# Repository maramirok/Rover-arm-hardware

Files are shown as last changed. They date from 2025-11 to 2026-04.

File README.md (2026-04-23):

# Rover Arm Hardware

Custom motor control PCB for the Space Concordia Mars rover robotic arm, designed in KiCad.

## Overview

The board drives five independent DC motors on the rover arm, receives commands over CAN from the main rover controller, and provides regulated power rails for the MCU and peripherals.

## Specifications

- **MCU:** STM32G030C8T6
- **CAN controller/transceiver:** MCP25625 (SPI interface)
- **Motor outputs:** 5 independent channels with PWM speed control and direction signals
- **Power input:** 16V DC
- **Regulation:** Buck converter  + LDO (MCU/logic supply)

## Contents

- `Schematics/` — KiCad schematic files
- `PCB/` — KiCad PCB layout files
- `Gerbers/` — Fabrication output files
- `BOM/` — Bill of materials

## Tools

Designed in KiCad. Open the project file in KiCad to view schematics and layout.

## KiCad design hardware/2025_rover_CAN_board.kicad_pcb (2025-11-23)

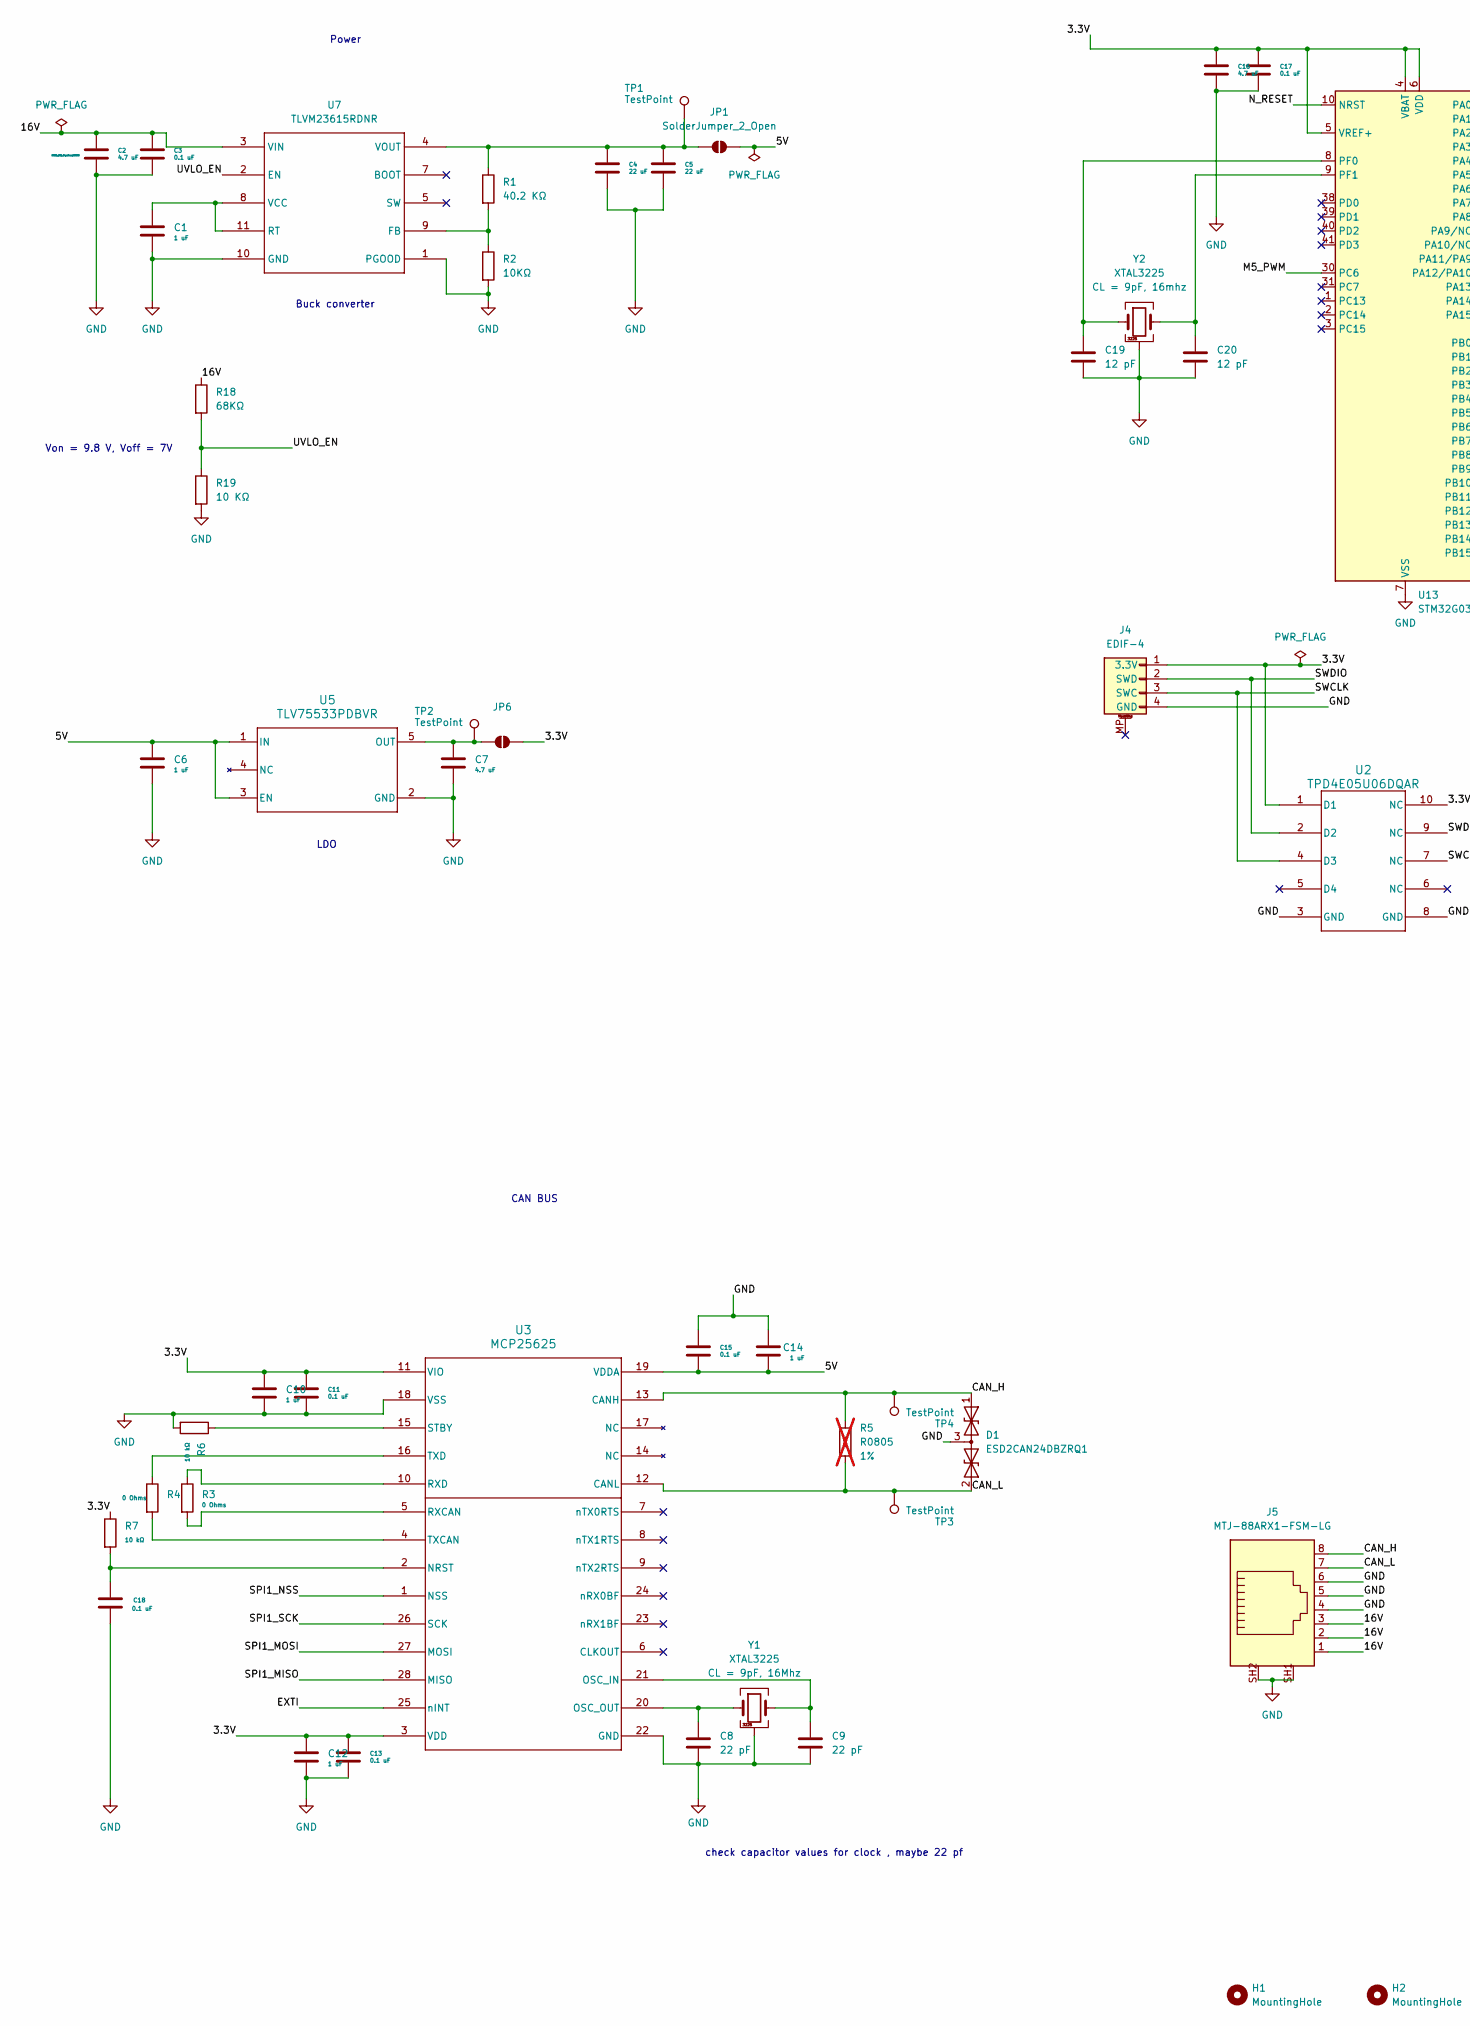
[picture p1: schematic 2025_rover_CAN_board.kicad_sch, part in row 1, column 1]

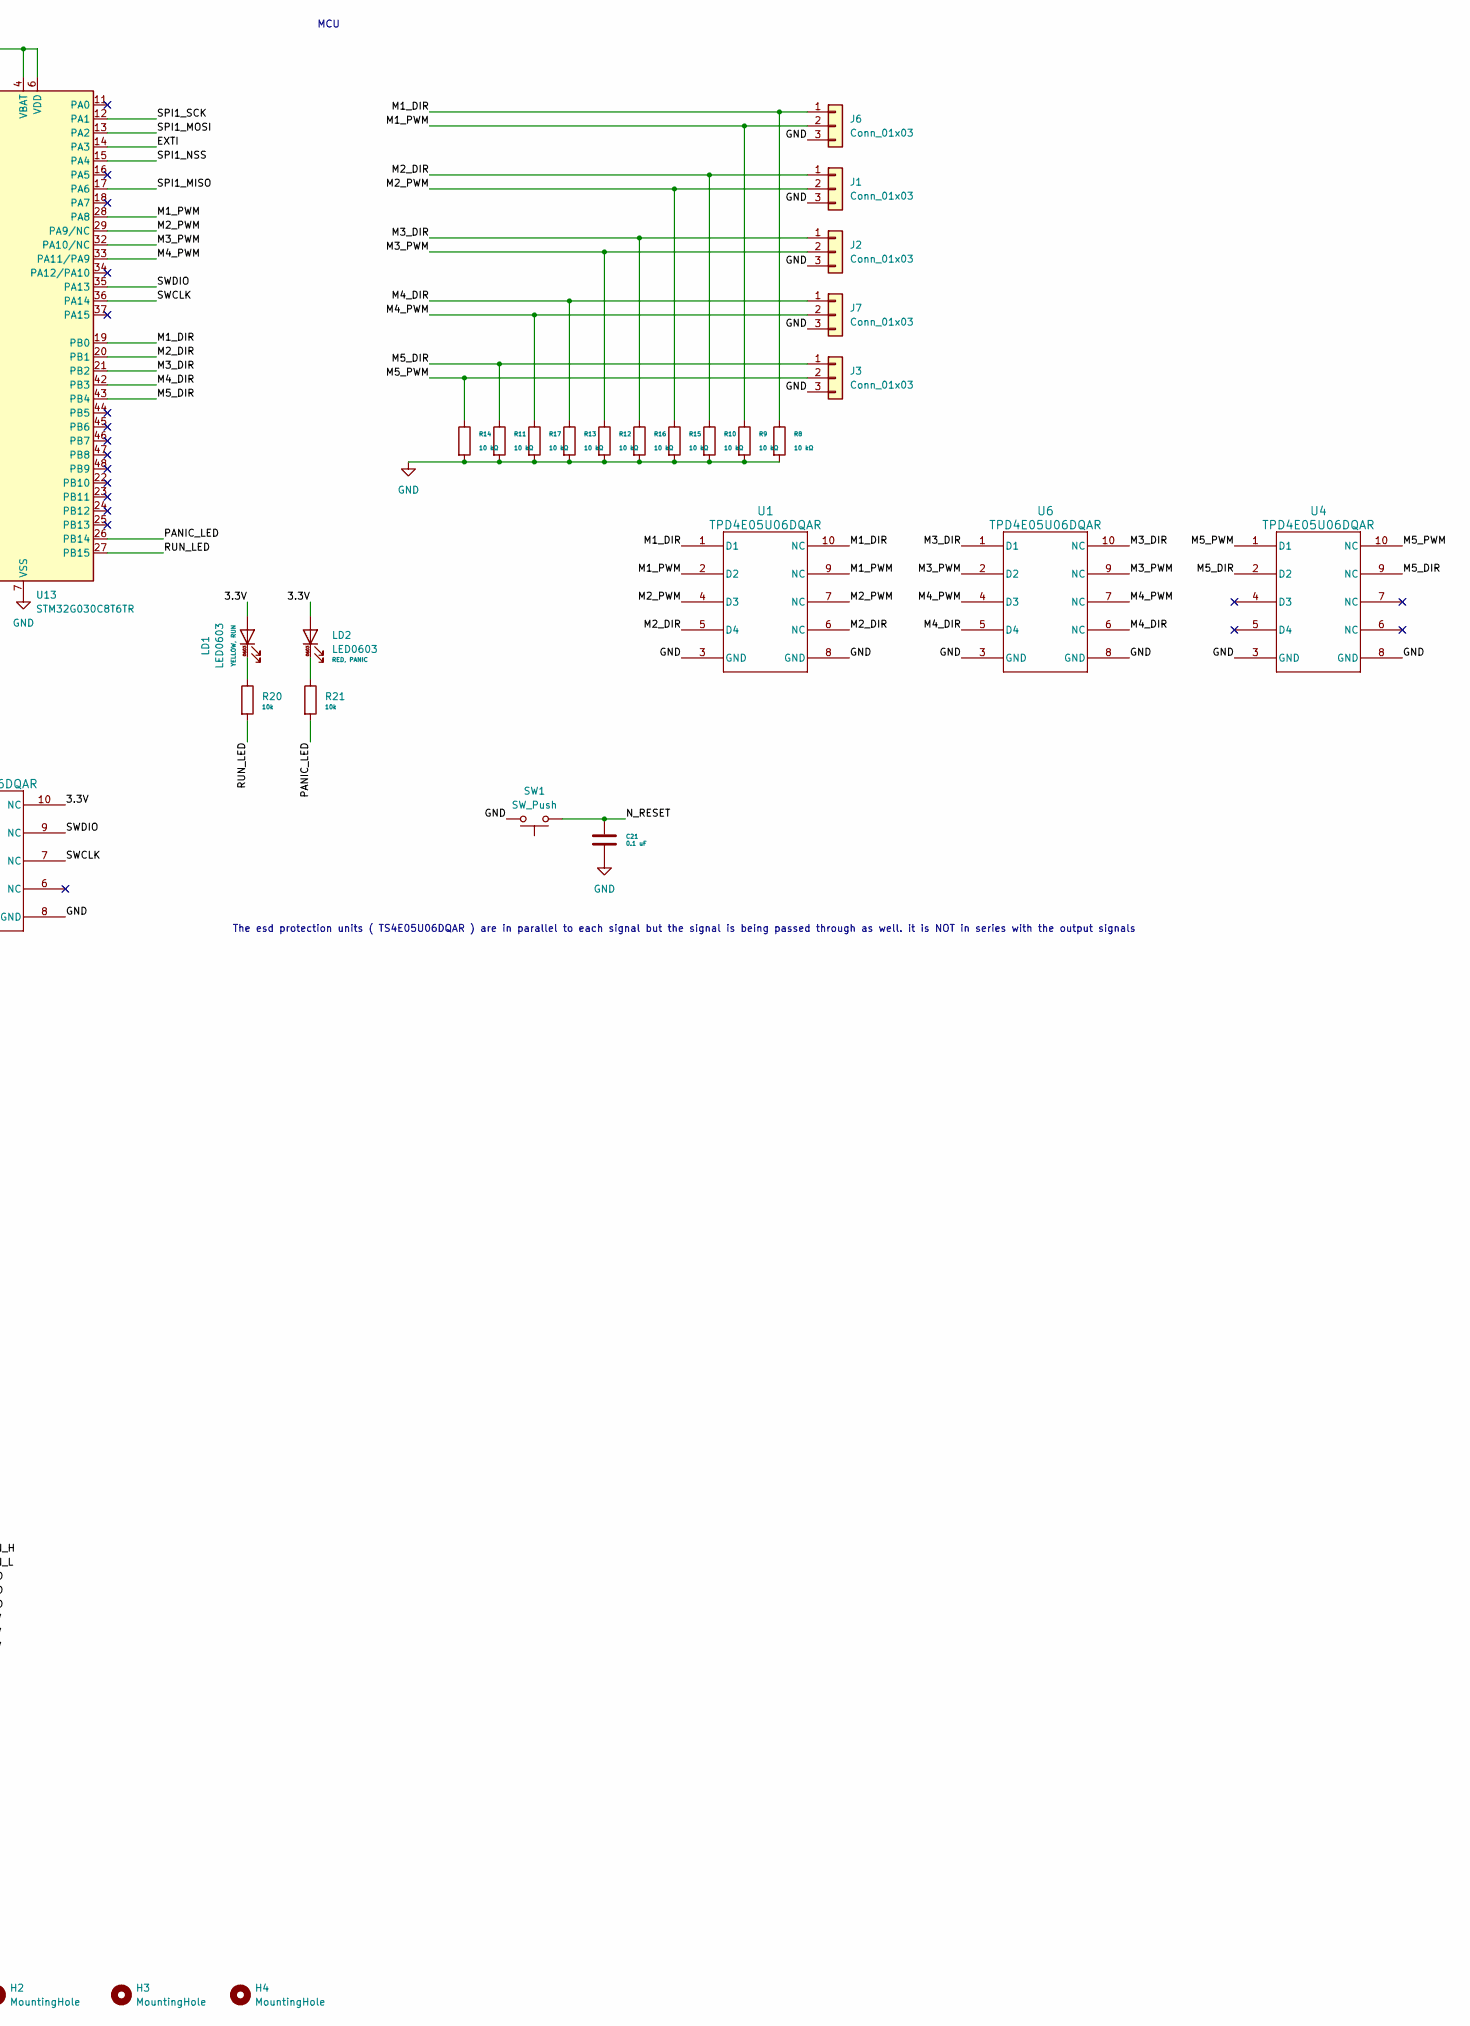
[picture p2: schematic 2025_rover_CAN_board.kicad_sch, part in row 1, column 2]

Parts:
C1, C10, C12, C14: 1 uF; C0402
C2, C7, C16: 4.7 uF; C0805
C3, C11, C13, C15, C17, C18: 0.1 uF; C0402
C4, C5: 22 uF; C0805
C6: 1 uF; C0805
C8, C9: 22 pF; C0402
C19, C20: 12 pF; C0402
C21: 0.1 uF; C0603
D1: ESD2CAN24DBZRQ1; SOT-23_DBZ_TEX
H1, H2, H3, H4: MountingHole; MountingHole_3.2mm_M3
J1, J2, J3, J6, J7: Conn_01x03; JST_XH_S3B-XH-A-1_1x03_P2.50mm_Horizontal
J4: EDIF-4; JST-GH-BM04B-GHS-TBT
J5: MTJ-88ARX1-FSM-LG; ADAMTECH_MTJ-88ARX1-FSM-LG
JP1, JP6: SolderJumper_2_Open; SolderJumper-2_P1.3mm_Open_TrianglePad1.0x1.5mm
LD1, LD2: LED0603
R1: 40.2 KΩ; R0402
R2: 10KΩ; R0402
R3, R4: 0 Ohms; R0402
R5: R0805; not fitted
R6: 10 kΩ; R0805
R7, R8, R9, R10, R11, R12, R13, R14, R15, R16, R17: 10 kΩ; R0402
R18: 68KΩ; R0402
R19: 10 KΩ; R0402
R20, R21: 10k; R0402
SW1: SW_Push; SW_C913791
TP1, TP2, TP3, TP4: TestPoint; TestPoint_Pad_D2.0mm
U1, U2, U4, U6: TPD4E05U06DQAR; DQA0010A
U3: MCP25625; Microchip_ML28
U5: TLV75533PDBVR; DBV0005A
U7: TLVM23615RDNR; RDN0011A
U13: STM32G030C8T6TR; LQFP-48_7x7mm_P0.5mm
Y1, Y2: XTAL3225; SMD3225

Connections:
/3.3V: C10.1, C11.1, C12.1, C13.1, C16.1, C17.1, J4.1 (3.3V), JP6.2 (B), LD1.2 (A), LD2.2 (A), R7.1, U2.1 (D1), U2.10 (NC), U3.3 (VDD), U3.11 (VIO), U13.4 (VBAT), U13.5 (VREF+), U13.6 (VDD)
/5V: C6.1, C14.2, C15.2, JP1.2 (B), U3.19 (VDDA), U5.1 (IN), U5.3 (EN)
/16V: C2.1, C3.1, J5.1, J5.2, J5.3, R18.1, U7.3 (VIN)
/CAN_H: D1.1 (A1), J5.8, R5.1, TP4.1, U3.13 (CANH)
/CAN_L: D1.2 (A2), J5.7, R5.2, TP3.1, U3.12 (CANL)
/EXTI: U3.25 (nINT), U13.14 (PA3)
/M1_DIR: J6.1, R8.1, U1.1 (D1), U1.10 (NC), U13.19 (PB0)
/M1_PWM: J6.2, R9.1, U1.2 (D2), U1.9 (NC), U13.28 (PA8)
/M2_DIR: J1.1, R10.1, U1.5 (D4), U1.6 (NC), U13.20 (PB1)
/M2_PWM: J1.2, R15.1, U1.4 (D3), U1.7 (NC), U13.29 (PA9/NC)
/M3_DIR: J2.1, R16.1, U6.1 (D1), U6.10 (NC), U13.21 (PB2)
/M3_PWM: J2.2, R12.1, U6.2 (D2), U6.9 (NC), U13.32 (PA10/NC)
/M4_DIR: J7.1, R13.1, U6.5 (D4), U6.6 (NC), U13.42 (PB3)
/M4_PWM: J7.2, R17.1, U6.4 (D3), U6.7 (NC), U13.33 (PA11/PA9)
/M5_DIR: J3.1, R11.1, U4.2 (D2), U4.9 (NC), U13.43 (PB4)
/M5_PWM: J3.2, R14.1, U4.1 (D1), U4.10 (NC), U13.30 (PC6)
/N_RESET: C21.1, SW1.1, U13.10 (NRST)
/PANIC_LED: R21.2, U13.26 (PB14)
/RUN_LED: R20.2, U13.27 (PB15)
/SPI1_MISO: U3.28 (MISO), U13.17 (PA6)
/SPI1_MOSI: U3.27 (MOSI), U13.13 (PA2)
/SPI1_NSS: U3.1 (NSS), U13.15 (PA4)
/SPI1_SCK: U3.26 (SCK), U13.12 (PA1)
/SWCLK: J4.3 (SWC), U2.4 (D3), U2.7 (NC), U13.36 (PA14)
/SWDIO: J4.2 (SWD), U2.2 (D2), U2.9 (NC), U13.35 (PA13)
/UVLO_EN: R18.2, R19.1, U7.2 (EN)
GND: C1.2, C2.2, C3.2, C4.2, C5.2, C6.2, C7.2, C8.2, C9.2, C10.2, C11.2, C12.2, C13.2, C14.1, C15.1, C16.2, C17.2, C18.2, C19.2, C20.2, C21.2, D1.3 (common), J1.3, J2.3, J3.3, J4.4 (GND), J5.4, J5.5, J5.6, J5.SH1, J5.SH2, J6.3, J7.3, R2.2, R6.2, R8.2, R9.2, R10.2, R11.2, R12.2, R13.2, R14.2, R15.2, R16.2, R17.2, R19.2, SW1.2, U1.3 (GND), U1.8 (GND), U2.3 (GND), U2.8 (GND), U3.18 (VSS), U3.22 (GND), U3.29 (EPAD), U4.3 (GND), U4.8 (GND), U5.2 (GND), U6.3 (GND), U6.8 (GND), U7.1 (PGOOD), U7.10 (GND), U13.7 (VSS), Y1.2, Y1.4, Y2.2, Y2.4
unnamed: C4.1, C5.1, JP1.1 (A), R1.1, TP1.1, U7.4 (VOUT)
unnamed: C7.1, JP6.1 (A), TP2.1, U5.5 (OUT)
unnamed: LD1.1 (K), R20.1
unnamed: LD2.1 (K), R21.1
unnamed: C18.1, R7.2, U3.2 (NRST)
unnamed: C9.1, U3.21 (OSC_IN), Y1.3
unnamed: C8.1, U3.20 (OSC_OUT), Y1.1
unnamed: R3.2, U3.5 (RXCAN)
unnamed: R3.1, U3.10 (RXD)
unnamed: R6.1, U3.15 (STBY)
unnamed: R4.2, U3.4 (TXCAN)
unnamed: R4.1, U3.16 (TXD)
unnamed: R1.2, R2.1, U7.9 (FB)
unnamed: C1.1, U7.8 (VCC), U7.11 (RT)
unnamed: C19.1, U13.8 (PF0), Y2.1
unnamed: C20.1, U13.9 (PF1), Y2.3

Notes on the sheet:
LDO
check capacitor values for clock , maybe 22 pf
CAN BUS
Buck converter
Von = 9.8 V, Voff = 7V
MCU
Power
The esd protection units ( TS4E05U06DQAR ) are in parallel to each signal but the signal is being passed through as well. it is NOT in series with the output signals

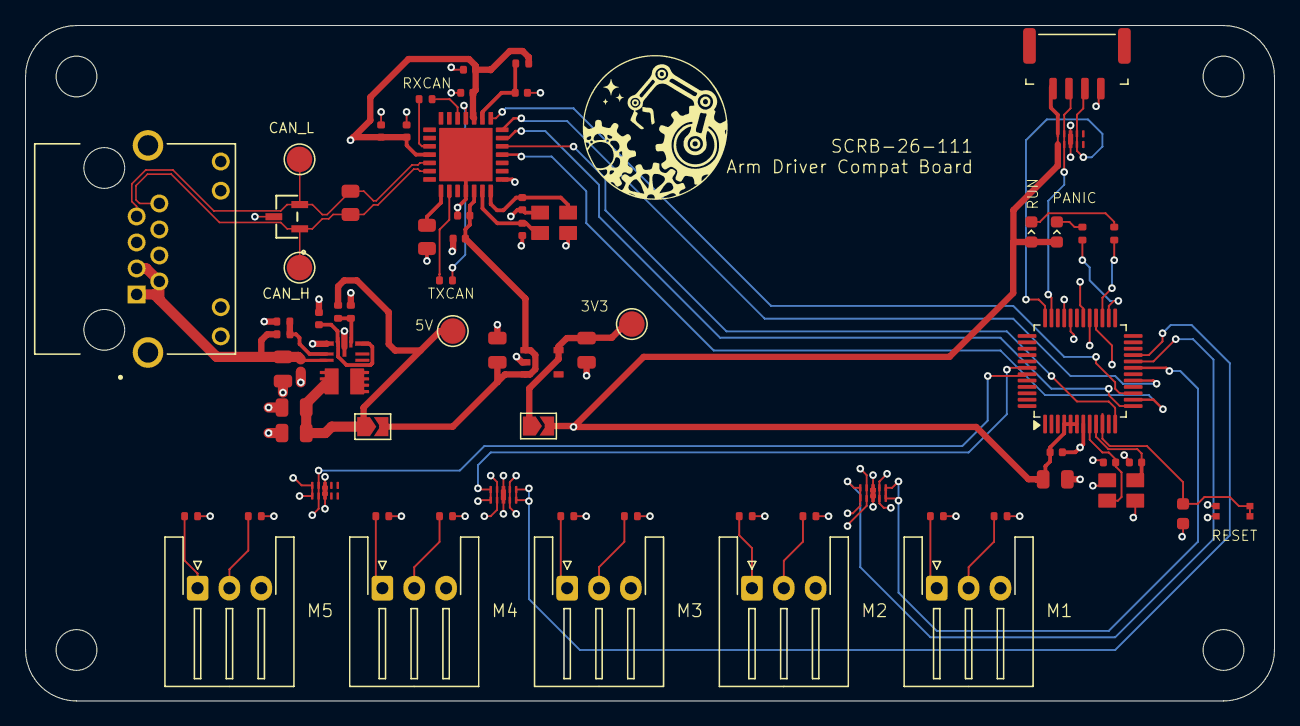
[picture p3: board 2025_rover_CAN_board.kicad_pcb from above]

Board: 4 copper layers, 98.0 x 53.0 mm, 73 parts (0 on the bottom side), 43 nets.

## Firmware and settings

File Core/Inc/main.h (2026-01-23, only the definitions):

#define MCP_INT_Pin GPIO_PIN_3
#define MCP_INT_GPIO_Port GPIOA
#define CS_Pin GPIO_PIN_4
#define CS_GPIO_Port GPIOA
#define M1_DIR_Pin GPIO_PIN_0
#define M1_DIR_GPIO_Port GPIOB
#define M2_DIR_Pin GPIO_PIN_1
#define M2_DIR_GPIO_Port GPIOB
#define M3_DIR_Pin GPIO_PIN_2
#define M3_DIR_GPIO_Port GPIOB
#define PANIC_LED_Pin GPIO_PIN_14
#define PANIC_LED_GPIO_Port GPIOB
#define RUN_LED_Pin GPIO_PIN_15
#define RUN_LED_GPIO_Port GPIOB
#define M1_PWM_Pin GPIO_PIN_8
#define M1_PWM_GPIO_Port GPIOA
#define M2_PWM_Pin GPIO_PIN_9
#define M2_PWM_GPIO_Port GPIOA
#define M5_PWM_Pin GPIO_PIN_6
#define M5_PWM_GPIO_Port GPIOC
#define M3_PWM_Pin GPIO_PIN_10
#define M3_PWM_GPIO_Port GPIOA
#define M4_PWM_Pin GPIO_PIN_11
#define M4_PWM_GPIO_Port GPIOA
#define M4_DIR_Pin GPIO_PIN_3
#define M4_DIR_GPIO_Port GPIOB
#define M5_DIR_Pin GPIO_PIN_4
#define M5_DIR_GPIO_Port GPIOB

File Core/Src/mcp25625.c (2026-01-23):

#include "mcp25625.h"
#include "stm32g0xx_hal.h"

static SPI_HandleTypeDef *mcp_hspi = NULL;
static GPIO_TypeDef *mcp_cs_port= NULL;
static uint16_t mcp_cs_pin =0;





static inline bool MCP_confirm_attach(void) {
	return (mcp_hspi !=NULL && mcp_cs_port !=NULL);
}


static inline void CS_low(void) {
	HAL_GPIO_WritePin(mcp_cs_port, mcp_cs_pin, GPIO_PIN_RESET);
}




static inline void CS_high(void) {
	HAL_GPIO_WritePin(mcp_cs_port, mcp_cs_pin, GPIO_PIN_SET);
}

void MCP_attach(SPI_HandleTypeDef *hspi, GPIO_TypeDef *cs_port, uint16_t cs_pin) {
	
	mcp_hspi = hspi;
	mcp_cs_port = cs_port;
	mcp_cs_pin = cs_pin;
	CS_high();
}



void MCP_reset(void)
{
    uint8_t cmd = MCP_CMD_RESET;

    CS_low();
    (void)HAL_SPI_Transmit(mcp_hspi, &cmd, 1, HAL_MAX_DELAY);
    CS_high();

    HAL_Delay(2); 
}

uint8_t MCP_read_byte(uint8_t address)
{
	
	if (!MCP_confirm_attach()) {
		return 0xFF;
	}
    uint8_t tx[3] = { MCP_CMD_READ, address, 0x00 };
    uint8_t rx[3] = { 0 };

    CS_low();
    (void)HAL_SPI_TransmitReceive(mcp_hspi, tx, rx, 3, HAL_MAX_DELAY);
    CS_high();

    return rx[2];
}

void MCP_write_byte (uint8_t address, uint8_t value)
{
	if (!MCP_confirm_attach()) {
			return 0xFF;
		}
	
    uint8_t tx[3] = { MCP_CMD_WRITE, address, value };

    CS_low();
    (void)HAL_SPI_Transmit(mcp_hspi, tx, 3, HAL_MAX_DELAY);
    CS_high();
}

void MCP_bit_modify(uint8_t address, uint8_t mask, uint8_t data)
{
	
	if (!MCP_confirm_attach()) {
			return 0xFF;
		}
    uint8_t tx[4] = { MCP_CMD_BIT_MODIFY, address, mask, data };

    CS_low();
    (void)HAL_SPI_Transmit(mcp_hspi, tx, 4, HAL_MAX_DELAY);
    CS_high();
}

static bool MCP_confirm_mode(uint8_t mode ) {
	uint8_t canstat = MCP_read_byte(MCP_CANSTAT);
	uint8_t canctrl = MCP_read_btye(MCP_CANCTRL);
	
	return (((canstat >>5) & 0x07) == (mode & 0x07));
	return (((canctrl >>5) & 0x07) == (mode & 0x07));
	
}

bool MCP_init(void) {
	
	if (!MCP_confirm_attach()) {
		return false;
	}
	
	
	MCP_reset();
	
	if (!MCP_confirm_mode(0b100)) {
		return false;
	}
	
	MCP_write_byte(MCP_CNF1, 0xC0);
	MCP_write_byte(MCP_CNF2, 0x9E);
	MCP_write_byte(MCP_CNF3, 0x03);
	
	MCP_bit_modify(MCP_CANCTRL, 0xE0, 0x00);
	
	HAL_Delay(2);
	
	if (!MCP_confirm_mode(0b000)) {
		return false;
	}
	
	return true;
	
	
}

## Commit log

2025-10-30 Create schematic
2025-11-01 Add files via upload
    rough draft of pcb layout, routing still needs to be done
    [2025_rover_CAN_board.kicad_pcb]
2026-01-23 Initial commit: STM32 firmware + MCP25625 driver
2026-01-23 Move STM32CubeIDE firmware files into firmware directory
2026-01-23 update to code
    [2025_rover_CAN_board.kicad_pcb, 2025_rover_CAN_board.kicad_sch, bill-of-materials-template-08 (1).xlsx]
2026-01-24 Move STM32 project into firmware/ folder
2026-01-31 Add polling-based CAN RX handling and error detection for MCP25625
    [main.h, mcp25625.c, scrb_111_2025_2.ioc]
2026-02-14 Update CAN driver
2026-02-14 Update MCP25625 driver
2026-02-21 Update MCP25625 driver: add frame packing/unpacking
2026-03-12 Updated firmware drivers and header files
2026-03-13 feat: complete motor control firmware with CAN, PWM, and error handling
    [scrb_111_2025_2.ioc]
2026-04-08 Add error handling state machine with CAN error flags and LED indicators
    [mcp25625.c]

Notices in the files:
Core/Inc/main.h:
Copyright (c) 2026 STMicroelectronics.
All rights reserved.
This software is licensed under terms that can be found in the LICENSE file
